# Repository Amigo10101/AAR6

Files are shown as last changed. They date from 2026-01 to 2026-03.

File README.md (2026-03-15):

# AAR6: 6-DOF Robotic Manipulator

AAR6 is a  6-DOF (Degrees of Freedom) desktop robotic arm ecosystem. This project integrates motion control, custom hardware design, and interactive 3D visualization into a unified platform. It is based on the open-source **PAROL6** design by Source Robotics, heavily modified with custom electronics and a robust QP-based differential controller.

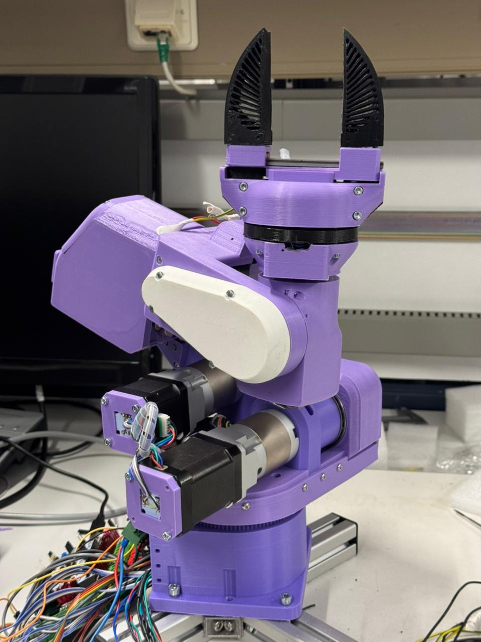
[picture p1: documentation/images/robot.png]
Robot View
 

## 📂 Project Structure

This repository is organized as a monorepo containing all sub-systems of the AAR6 robot:

### 1. [MCU Firmware (STM32)](mcu_firmware/)
The low-level "brain" of the robot, running on an **STM32F446** microcontroller.
- **Real-Time Control**: Implements a 20kHz motion engine for smooth step generation.
- **S-Curve Profiles**: Uses 7-segment S-curve trajectories to minimize jerk and vibrations.
- **Driver Interface**: Communicates with **TMC5160** stepper drivers via SPI.
- **Telemetry**: Streams high-frequency joint states and system health to the host PC.

### 2. [Robot Controller (CPP/QT)](Robot_controller/)
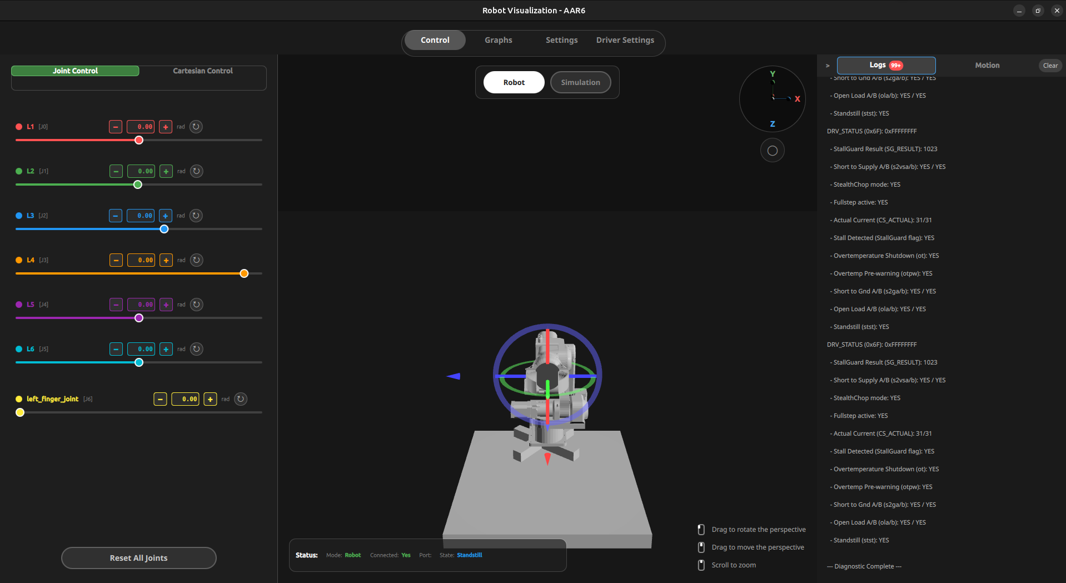
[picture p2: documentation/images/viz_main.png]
Software Interface

The advanced kinematic engine and 3D visualization suite.
- **Kinematics Engine**: High-performance Forward and Inverse Kinematics (FK/IK) implementation.
- **Differential QP Controller**: A singularity-robust solver using Selective Damped Least Squares (SDLS) and Quadratic Programming (OSQP).
- **3D Visualization**: A Qt/QML based interface for real-time monitoring, gizmo-driven movement, and simulator functionality.
- **Collision Checking**: Integrated environment awareness for safe motion planning.

### 3. [Control Board (KiCad)](control_board/)
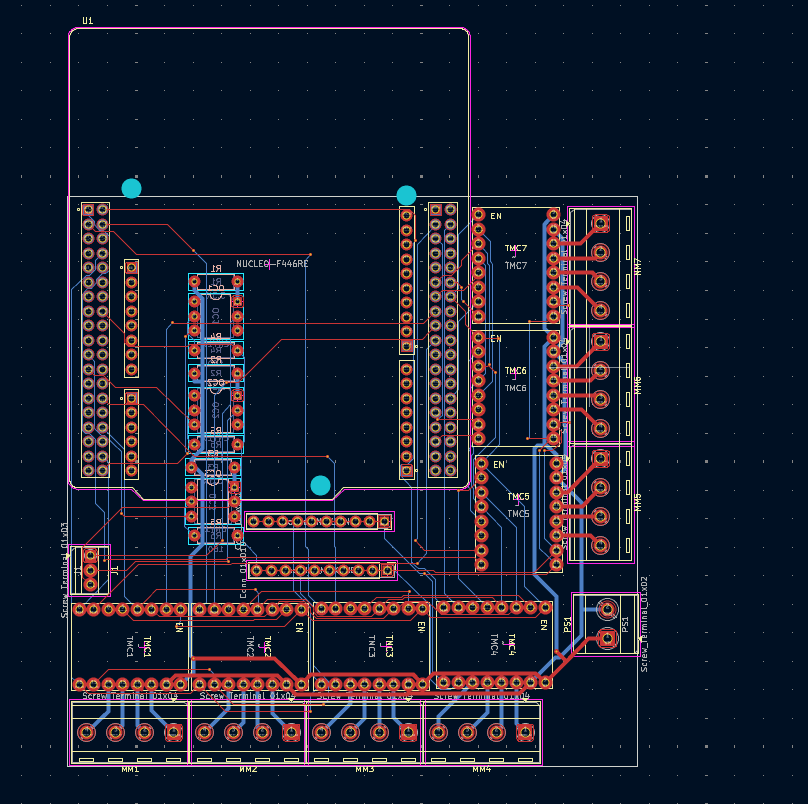
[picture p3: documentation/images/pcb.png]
PCB Design

Custom PCB design (KiCad) that integrates all electronic components.
- **Motor Control**: Supports 7× TMC5160 drivers (6 joints + 1 gripper).
- **Sensor Integration**: Interfaces for AS5600 magnetic encoders and limit switches.
- **Connectivity**: High-speed USB tracking and power distribution logic.

### 4. [ROS 2 Workspace](Robot_ros2_ws/)
Integration layer for the Robot Operating System (ROS 2 Jazzy).
- **Environment**: Containerized ROS 2 development via Docker.
- **Bridging**: Scripts to bridge URDF standalone commands to standard ROS 2 topics.
- **MoveIt Support**: Configuration files for advanced trajectory planning.

### 5. [Documentation](documentation/)
Technical reports, schematics, and academic documentation.
- **Technical Report**: Detailed LaTeX documentation covering mathematics, hardware specs, and software architecture.
- **Schematics**: PDF and image exports of the electrical design.

---

## 🚀 Key Features

- **Singularity Robustness**: Graceful handling of wrist, shoulder, and elbow singularities using adaptive damping.
- **Interactive Control**: Move the robot via 3D gizmos, joint sliders, or direct Cartesian input.
- **Optimized Communication**: 921,600 baud DMA-based serial link for low-latency host-to-MCU coordination.

---

## 🛠️ Components Overview

| Component | Technology | Detail |
| :--- | :--- | :--- |
| **Microcontroller** | STM32F446RET6 | ARM Cortex-M4 @ 180MHz |
| **Motor Drivers** | TMC5160 | 32 microsteps, StallGuard support |
| **GUI Framework** | Qt 6 / QML | Hardware-accelerated 3D rendering |
| **Optimization** | OSQP | Convex Quadratic Programming solver |
| **Communication** | USB-CDC | Custom binary protocol with CRC |

---

## 📜 Documentation & Attribution
- **Mechanical Design**: [PAROL6 by Source Robotics](https://source-robotics.github.io/PAROL-docs/)
- **Core Libraries**:
  - [EAIK (Eigen-based Analytical Inverse Kinematics)](https://github.com/OstermD/EAIK) - Primary analytical seeder for IK.
  - [OSQP (Operator Splitting QP Solver)](https://github.com/osqp) - Numerical optimization for differential control.
  - [FCL (Flexible Collision Library)](https://github.com/flexible-collision-library/fcl) - Real-time collision checking and environment awareness.

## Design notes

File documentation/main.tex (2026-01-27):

%%%%%%%%%%%%%%%%%%%%%%%%%%%%%%%%%%%%%%%%%
% 6-DOF Robotic Arm - Project Report
%%%%%%%%%%%%%%%%%%%%%%%%%%%%%%%%%%%%%%%%%

\documentclass[12pt,a4paper]{report}

% Basic packages
\usepackage[utf8]{inputenc}
\usepackage[T1]{fontenc}
\usepackage{lmodern}
\usepackage[english]{babel}
\usepackage{geometry}
\geometry{margin=2.5cm}

% Graphics
\usepackage{graphicx}
\usepackage{float}

% Tables
\usepackage{booktabs}
\usepackage{tabularx}

% Code listings
\usepackage{listings}
\usepackage{xcolor}

% Math
\usepackage{amsmath}
\usepackage{amssymb}

% TikZ for diagrams
\usepackage{tikz}
\usetikzlibrary{shapes,arrows,positioning,fit}

% Hyperlinks
\usepackage{hyperref}
\hypersetup{colorlinks=true, linkcolor=blue!60!black}

% Code style
\lstset{
    basicstyle=\ttfamily\small,
    breaklines=true,
    frame=single,
    backgroundcolor=\color{gray!10}
}

%% ========================================
%% DOCUMENT INFO
%% ========================================

\title{
    \vspace{2cm}
    {\Huge\bfseries Design and Implementation of a}\\[0.3cm]
    {\Huge\bfseries 6-DOF Robotic Manipulator}\\[0.5cm]
    {\Huge\bfseries with Singularity-Robust Motion Control}\\[0.8cm]
    {\LARGE Project Report}\\
    \vspace{2cm}
}

\author{
    Anwesh Rijal (16940572) \\
    Austin Mathew Palamoottil (26044014) \\
    \textit{Hochschule Ravensburg-Weingarten University}
}

\date{
    January 2026
}

%% ========================================
%% DOCUMENT
%% ========================================

\begin{document}

% Title page
\maketitle
\thispagestyle{empty}
\newpage

% Table of contents
\tableofcontents
\newpage

%% ========================================
%% PART 1: INTRODUCTION
%% ========================================

\chapter{Introduction}

\section{Project Background}

This project involves the development of a 6-DOF robotic arm control system, including custom firmware and host software. The mechanical design is based on the open-source \textbf{PAROL6} desktop robot arm developed by Source Robotics.

\subsection{Base Design Attribution}

The robot hardware design used in this project is derived from:

\begin{itemize}
    \item \textbf{PAROL6 Desktop Robot Arm} by Source Robotics
    \item Design by Petar Crnjak (\url{https://github.com/PCrnjak})
    \item Documentation: \url{https://source-robotics.github.io/PAROL-docs/}
    \item Hardware: \url{https://github.com/PCrnjak/PAROL6-Desktop-robot-arm}
\end{itemize}

This project extends the base PAROL6 design with custom firmware and software implementations.

\section{Project Objectives}

The primary objectives of this project are:

\begin{enumerate}
    \item \textbf{Build a Fully Functional 6-DOF Robotic Arm}: Assemble and integrate the mechanical structure, stepper motors, control electronics, and end effector into a working desktop manipulator.
    
    \item \textbf{Develop Stable Motion Control Software}: Implement a robust inverse kinematics controller capable of smooth, singularity-free motion throughout the workspace.
    
    \item \textbf{Implement Real-Time Control}: Create firmware and host software that can execute motion commands with low latency and high precision.
\end{enumerate}

\subsection{Controller Objectives}

The motion controller specifically aims to:
\begin{itemize}
    \item Provide stable velocity-level IK using quadratic programming (QP)
    \item Handle kinematic singularities gracefully using adaptive damping
    \item Support real-time interactive control via visualization interface
    \item Respect joint position and velocity limits at all times
\end{itemize}

\subsection{Software Architecture}

The control software consists of two main components:

\begin{itemize}
    \item \textbf{MCU Firmware} (STM32F446): Handles low-level motor control, step generation, S-curve motion profiles, and serial communication with the host.
    
    \item \textbf{Host Software} (C++/Qt): Implements kinematics computation (FK/IK), the QP-based differential controller with singularity handling, and 3D visualization for interactive control.
\end{itemize}

\section{Scope}

This project covers:
\begin{itemize}
    \item Mechanical assembly of the PAROL6-based robot arm
    \item Custom control board with STM32F446 and TMC5160 drivers
    \item MCU firmware for motion execution
    \item Host-side kinematics and motion control software
    \item 3D visualization and user interface
\end{itemize}

\section{Document Structure}

\begin{itemize}
    \item \textbf{Chapter 2 - Hardware}: Robot mechanical design, control board, electrical connections
    \item \textbf{Chapter 3 - MCU Firmware}: Motor control, S-curve profiles, communication
    \item \textbf{Chapter 4 - Motion Control Software}: Kinematics, QP-based differential controller, visualization
    \item \textbf{Appendices}: Pinout, DH parameters, joint limits
\end{itemize}

%% ========================================
%% PART 2: HARDWARE
%% ========================================

\chapter{Hardware}

This chapter describes the physical hardware of the our robotic arm system.

%% --- Section 1: The Robot ---
\section{The Robot}

\subsection{Overview}

Our robot is based on the \textbf{PAROL6} open-source robot arm design by Source Robotics. It is a 6 degrees of freedom (6-DOF) desktop robotic arm designed for education, research, and light industrial applications. The robot features an articulated arm configuration with all revolute joints, providing full spatial manipulation capability.

The mechanical design, including 3D printed parts and assembly, follows the original PAROL6 specifications with modifications for this project.

\begin{table}[H]
    \centering
    \begin{tabular}{|l|l|}
        \hline
        \textbf{Parameter} & \textbf{Value} \\
        \hline
        Degrees of Freedom & 6 rotating joints \\
        Weight & 5.5 kg \\
        Power Consumption & 40 W \\
        Material & 3D printed ABS plastic \\
        Communication & USB \\
        \hline
    \end{tabular}
    \caption{Robot Specifications}
    \label{tab:robot_specs}
\end{table}

\subsection{Mechanical Structure}

The robot is constructed primarily from 3D printed ABS plastic. ABS provides good mechanical strength and thermal resistance for this application.

\subsubsection{Joint Configuration}

\begin{table}[H]
    \centering
    \begin{tabular}{|c|l|c|l|}
        \hline
        \textbf{Joint} & \textbf{Function} & \textbf{Range} & \textbf{Reduction} \\
        \hline
        J1 & Base rotation & 250° & Belt 6.4:1 \\
        J2 & Shoulder lift & 141° & Planetary 20:1 \\
        J3 & Elbow bend & 180° & Planetary 20:1 + Belt 38:42 \\
        J4 & Wrist rotation & 212° & Belt 4:1 \\
        J5 & Wrist pitch & 180° & Belt 4:1 \\
        J6 & Tool rotation & $\infty$ & Planetary 10:1 \\
        \hline
    \end{tabular}
    \caption{Joint Configuration and Reduction Ratios}
    \label{tab:joint_config}
\end{table}

\subsubsection{Spherical Wrist Design}

The robot uses a \textbf{spherical wrist} configuration, where the last three joint axes (J4, J5, J6) intersect at a single point called the wrist center. This design is common in industrial manipulators and simplifies inverse kinematics by decoupling position and orientation problems.

\subsubsection{Kinematic Singularities}

Singularities are configurations where the robot loses one or more degrees of freedom. For our 6-DOF spherical wrist arm, three main singularities exist:

\begin{enumerate}
    \item \textbf{Wrist Singularity}: Occurs when J4 and J6 axes align (J5 = 0° or 180°)
    \item \textbf{Shoulder Singularity}: Wrist center lies on the J1 axis
    \item \textbf{Elbow Singularity}: Arm fully extended or folded
\end{enumerate}

Near singularities, the inverse Jacobian produces very large joint velocities, causing instability. Our software mitigates this using adaptive damping techniques (see Chapter 4).

\subsection{Actuators}

All joints use stepper motors with the following configuration:

\begin{itemize}
    \item \textbf{Motor type}: NEMA 17 / NEMA 23 stepper motors
    \item \textbf{Steps per revolution}: 200 (1.8° step angle)
    \item \textbf{Microstepping}: 32 microsteps (6400 steps/revolution)
    \item \textbf{Drivers}: TMC5160 (BigTreeTech) with StallGuard \cite{tmc5160_prod}
    \item \textbf{Gearboxes}: Precision planetary gearboxes and belt drives
\end{itemize}

\subsubsection{Step Resolution}

With 32 microstepping and gear reduction, the theoretical step resolution at each joint:

\begin{table}[H]
    \centering
    \begin{tabular}{|c|c|c|}
        \hline
        \textbf{Joint} & \textbf{Resolution (rad)} & \textbf{Resolution (deg)} \\
        \hline
        J1 & 0.000153 & 0.00879° \\
        J2 & 0.000049 & 0.00281° \\
        J3 & 0.000054 & 0.00311° \\
        J4 & 0.000245 & 0.01406° \\
        J5 & 0.000245 & 0.01406° \\
        J6 & 0.000098 & 0.00563° \\
        \hline
    \end{tabular}
    \caption{Joint Step Resolution (after gear reduction)}
    \label{tab:step_resolution}
\end{table}

\subsection{Sensors}

\begin{itemize}
    \item \textbf{Position sensing}: AS5600 magnetic encoders for closed-loop position feedback
    \item \textbf{Limit switches}: Used for homing and end-of-travel protection
\end{itemize}

\subsection{End Effector}

The end effector is a custom-designed electric gripper based on the \textbf{SSG-48 Adaptive Electric Gripper} by Source Robotics (\url{https://github.com/PCrnjak/SSG-48-adaptive-electric-gripper}).

\subsubsection{Gripper Redesign}

The original SSG-48 design was heavily modified for this project:

\begin{itemize}
    \item \textbf{Actuation}: Replaced original motor with a stepper motor for precise position control
    \item \textbf{Position Feedback}: Added AS5600 magnetic encoder for closed-loop gripper position sensing
    \item \textbf{Control}: Integrated with the main control system for coordinated motion
\end{itemize}

\subsubsection{Gripper Specifications}

\begin{table}[H]
    \centering
    \begin{tabular}{|l|l|}
        \hline
        \textbf{Parameter} & \textbf{Value} \\
        \hline
        Actuation & Stepper motor \\
        Position Sensor & AS5600 magnetic encoder \\
        Control Mode & Closed-loop position \\
        Base Design & SSG-48 (Source Robotics) \\
        \hline
    \end{tabular}
    \caption{Gripper Specifications}
    \label{tab:gripper_specs}
\end{table}

%% --- Section 2: Control Board ---
\section{Control Board}

\subsection{Overview}

A custom PCB was designed to integrate all control electronics for the robot. The board serves as the central interface between the STM32 microcontroller and all motor drivers, sensors, and power systems.

% TODO: Add PCB image
\begin{figure}[H]
    \centering
    
    \caption{Control Board PCB Layout}
    \label{fig:control_board_pcb}
\end{figure}

% TODO: Add 3D render
\begin{figure}[H]
    \centering
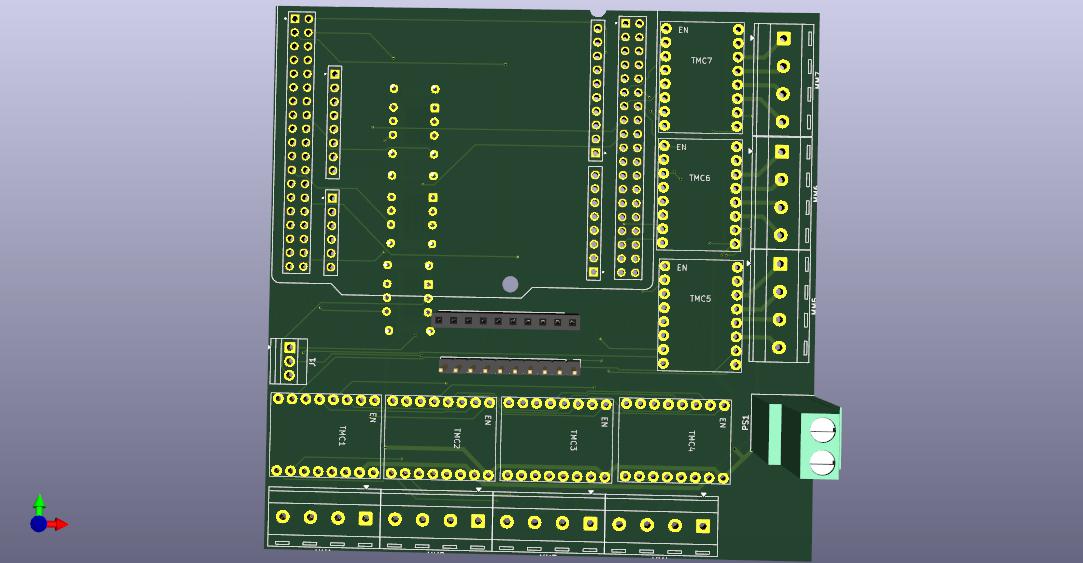
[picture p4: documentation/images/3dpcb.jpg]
    
    \caption{Control Board 3D View}
    \label{fig:control_board_3d}
\end{figure}

\subsubsection{Key Features}

\begin{itemize}
    \item \textbf{MCU Interface}: Socket for STM32 Nucleo development board
    \item \textbf{Motor Drivers}: 7× TMC5160 BigTreeTech driver slots (6 robot joints + 1 gripper)
    \item \textbf{Motor Outputs}: Connectors for all stepper motors
    \item \textbf{Limit Switches}: Input connectors for all joint limit switches
    \item \textbf{Power Interface}: Motor power input and distribution
\end{itemize}

\subsection{Microcontroller}

The control board uses an \textbf{STM32 Nucleo} development board as the main processor:
\begin{itemize}
    \item Plugs into dedicated socket on the control board
    \item Provides all GPIO, timer, and communication interfaces
    \item USB connection for host communication
    \item Firmware development and debugging via ST-Link
\end{itemize}

\subsection{Motor Drivers}

The board accommodates 7 \textbf{TMC5160 BigTreeTech} stepper drivers:

\begin{table}[H]
    \centering
    \begin{tabular}{|c|l|l|}
        \hline
        \textbf{Slot} & \textbf{Function} & \textbf{Motor} \\
        \hline
        1 & Joint 1 & Base rotation \\
        2 & Joint 2 & Shoulder \\
        3 & Joint 3 & Elbow \\
        4 & Joint 4 & Wrist 1 \\
        5 & Joint 5 & Wrist 2 \\
        6 & Joint 6 & Wrist 3 \\
        7 & Gripper & End effector \\
        \hline
    \end{tabular}
    \caption{Motor Driver Assignments}
    \label{tab:driver_assignments}
\end{table}

\subsection{Power System}

\begin{itemize}
    \item \textbf{Motor Power}: Direct connection for motor supply voltage
    \item \textbf{Logic Power}: Regulated from motor supply or USB
\end{itemize}

\subsection{Connectors}

\begin{itemize}
    \item \textbf{Motor outputs}: 7× stepper motor connectors (4-pin)
    \item \textbf{Limit switches}: Input connectors for each joint
    \item \textbf{Encoder inputs}: For AS5600 position feedback
    \item \textbf{Power input}: Main power connector
\end{itemize}

%% --- Section 3: Electrical Connections ---
\section{Electrical Connections}

This section presents the schematic diagrams for the main electrical subsystems.

\subsection{MCU Connections}

The STM32 Nucleo board interfaces with all other subsystems:

\begin{figure}[H]
    \centering
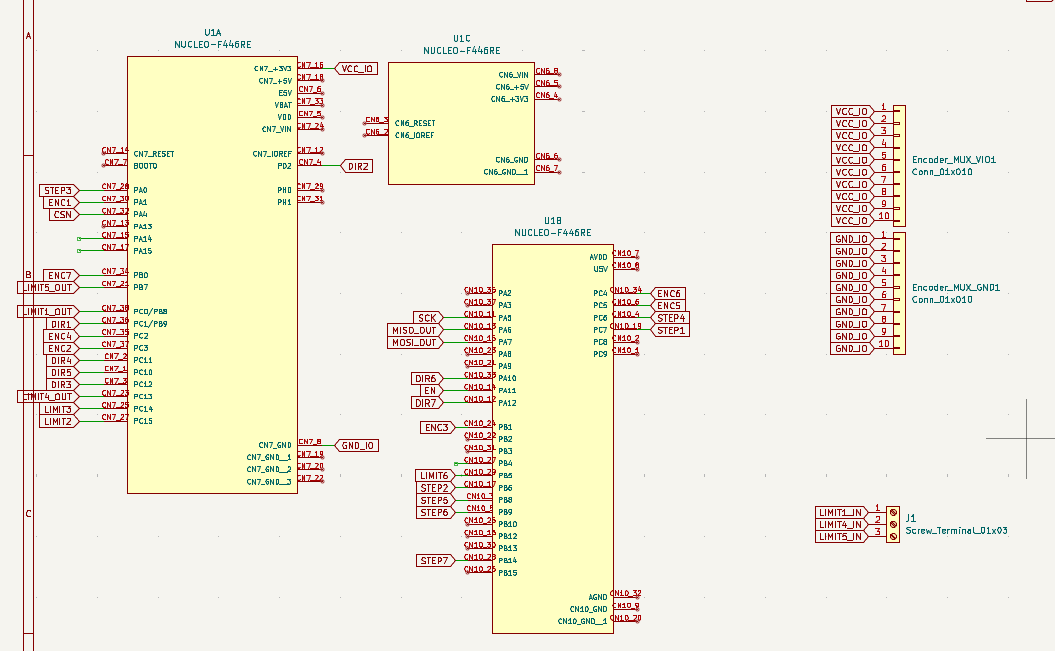
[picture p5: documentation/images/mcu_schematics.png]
    
    \caption{MCU Schematic - STM32 Nucleo Connections}
    \label{fig:mcu_schematic}
\end{figure}

\subsection{Motor Driver Wiring}

The TMC5160 motor drivers are connected via \textbf{SPI daisy chain} configuration. This allows all 7 drivers to share a single SPI bus, reducing the number of required GPIO pins.

\begin{figure}[H]
    \centering
    
    \caption{Motor Driver Schematic - SPI Daisy Chain Configuration}
    \label{fig:motor_schematic}
\end{figure}

\subsubsection{SPI Daisy Chain}

In daisy chain mode:
\begin{itemize}
    \item All drivers share common SCK (clock) and CS (chip select) lines
    \item Data passes from SDO of one driver to SDI of the next
    \item Single SPI transaction addresses all 7 drivers sequentially
    \item Reduces wiring complexity and MCU pin usage
\end{itemize}

\subsection{Limit Switch Wiring}

Each joint has a limit switch for homing and end-of-travel protection:

\begin{figure}[H]
    \centering
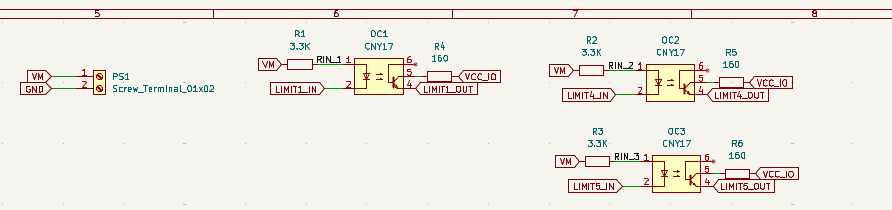
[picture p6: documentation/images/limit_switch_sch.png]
    
    \caption{Limit Switch Schematic}
    \label{fig:limit_switch_schematic}
\end{figure}

%% ========================================
%% PART 3: MCU FIRMWARE
%% ========================================

\chapter{MCU Firmware}

This chapter describes the firmware running on the STM32 Nucleo microcontroller.

\section{Firmware Overview}

The MCU firmware is responsible for real-time motor control, sensor reading, and communication with the host. It uses FreeRTOS for task management.

\subsection{System Architecture}

\begin{figure}[H]
    \centering
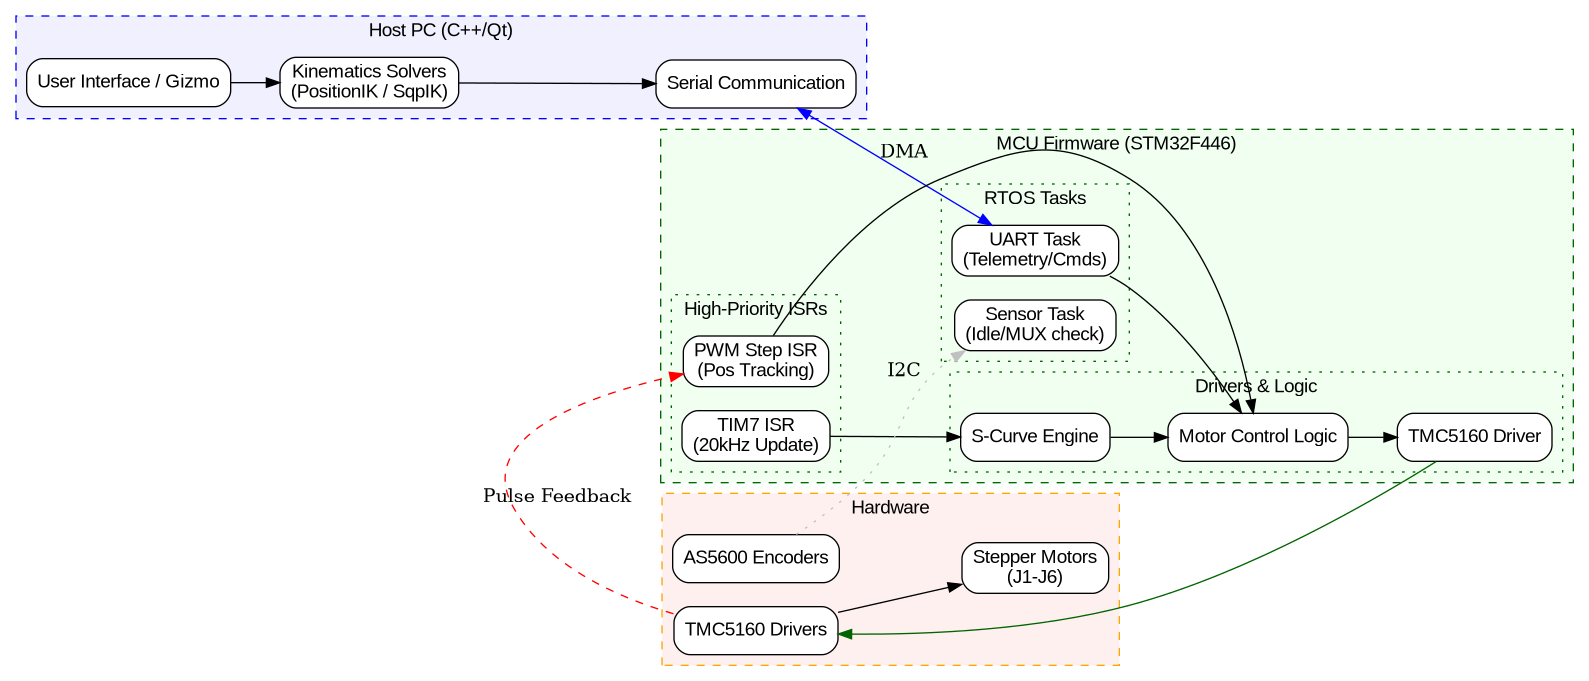
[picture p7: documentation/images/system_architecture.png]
    
    \caption{System Architecture and Data Flow across Host PC, MCU, and Hardware}
    \label{fig:system_architecture}
\end{figure}

\subsection{RTOS Tasks}

The firmware utilizes a hybrid architecture combining high-frequency interrupts for motion control with RTOS tasks for communication and low-priority monitoring:

\begin{table}[H]
    \centering
    \begin{tabular}{|l|l|l|}
        \hline
        \textbf{Component} & \textbf{Priority/Rate} & \textbf{Function} \\
        \hline
        TIM7 ISR & 20\,kHz & S-Curve engine update, PWM frequency modulation \\
        PWM Step ISR & Event-based & Real-time position tracking, target-reached stopping \\
        UART Task & High & DMA-based telemetry streaming and command parsing \\
        Sensor Task & Low & PCA9548A MUX detection and health monitoring \\
        \hline
    \end{tabular}
    \caption{Real-Time Software Components}
    \label{tab:realtime_components}
\end{table}

\section{Motor Control}

\subsection{TMC5160 Driver Interface}

The firmware communicates with TMC5160 drivers via SPI:
\begin{itemize}
    \item Daisy chain configuration for all 7 drivers
    \item Register access for current, velocity, and position control
    \item StallGuard feedback for sensorless homing
\end{itemize}

\subsection{Step Generation}

Motor steps are generated using hardware timers:
\begin{itemize}
    \item Timer-based step pulse generation
    \item Velocity and acceleration limiting
    \item Smooth start/stop transitions
\end{itemize}

The firmware implements a high-performance 7-segment S-Curve motion profile to ensure continuous acceleration and minimize mechanical vibrations. Unlike standard trapezoidal profiles, the S-Curve limits the third derivative of position (jerk), preventing the "infinite jerk" spikes that lead to motor skipping and structural resonance.

\subsection{Mathematical Foundation}

The motion profile is governed by the constant jerk $J$, which is the rate of change of acceleration $a$. The kinematic states are derived through successive integration:

\begin{equation}
    a(t) = a_0 + \int_{0}^{t} J(\tau) d\tau
\end{equation}
\begin{equation}
    v(t) = v_0 + \int_{0}^{t} a(\tau) d\tau = v_0 + a_0 t + \frac{1}{2} J t^2
\end{equation}
\begin{equation}
    s(t) = s_0 + \int_{0}^{t} v(\tau) d\tau = s_0 + v_0 t + \frac{1}{2} a_0 t^2 + \frac{1}{6} J t^3
\end{equation}

\subsection{The 7-Segment Profile}

A full point-to-point motion consists of seven distinct phases:

\begin{enumerate}
    \item \textbf{Jerk-up}: Jerk is constant ($+J_{max}$), acceleration increases linearly.
    \item \textbf{Constant Accel}: Jerk is zero, acceleration is constant ($a_{max}$).
    \item \textbf{Jerk-down}: Jerk is constant ($-J_{max}$), acceleration decreases to zero as velocity reaches the maximum setpoint.
    \item \textbf{Constant Velocity}: Jerk and acceleration are zero.
    \item \textbf{Jerk-down}: Jerk is constant ($-J_{max}$), acceleration linearly decreases (deceleration increases).
    \item \textbf{Constant Decel}: Jerk is zero, deceleration is constant ($-a_{max}$).
    \item \textbf{Jerk-up}: Jerk is constant ($+J_{max}$), deceleration returns to zero as the target position is reached.
\end{enumerate}

\subsection{Implementation Strategy}

The firmware executes this engine within the \textbf{TIM7 ISR at 20\,kHz}. This high frequency (50\,$\mu$s ticks) allows for quasi-continuous updates of the output PWM frequency, ensuring the motor follows the ideal curve with negligible quantization error.

\subsubsection{Adaptive Deceleration}
Because the MCU must handle dynamic target updates and external interruptions, the engine does not simply "blindly" run a pre-calculated curve. Instead, it performs a \textbf{deceleration check every 1\,ms}:
\begin{itemize}
    \item It continuously calculates the \textit{stopping distance} required to reach zero velocity from the current speed using maximum jerk/decel limits.
    \item When the \textit{remaining distance} to the target is less than or equal to the stopping distance, it triggers the transition from constant velocity to the deceleration phases (Phase 5).
    \item \textbf{Overshoot Correction}: In the final pulses (Phase 7), any remaining floating-point error is compensated by an adaptive "dist-remove-per-cycle" calculation, guaranteeing that the final pulse lands exactly on the integer step target.
\end{itemize}

\section{Communication Protocol}

Communication with the host software is implemented over a high-speed USB-CDC serial link (baud rate 921,600). The protocol uses a robust binary framing to ensure data integrity and low latency.

\subsection{Framing Structure}
All packets, regardless of direction, share a common header and footer structure:
\begin{itemize}
    \item \textbf{Start Frame}: \texttt{0xAA 0x55} (2 bytes)
    \item \textbf{Length}: Payload size (2 bytes, Little-Endian)
    \item \textbf{Payload}: Actual data (variable length)
    \item \textbf{Checksum}: XOR sum of all payload bytes (1 byte)
\end{itemize}

\subsection{Outgoing Format (MCU $\rightarrow$ PC)}
The MCU streams telemetry at 100\,Hz. The primary telemetry packet (Type \texttt{0x01}) payload consists of:
\begin{itemize}
    \item \textbf{Joint Data}: 6 joints $\times$ (Position, Velocity, Acceleration) as 32-bit floats (72 bytes total)
    \item \textbf{Robot State}: 1 byte integer (Current operational mode)
\end{itemize}

\subsection{Incoming Format (PC $\rightarrow$ MCU)}
The host sends control and motion commands. The payload structure varies by command type:
\begin{itemize}
    \item \textbf{State Commands}: 1 byte (e.g., CMD\_ESTOP, CMD\_HOME)
    \item \textbf{Motion Commands}: 2 bytes (Command Type + Action) followed by 6 joints $\times$ (Position, Velocity) as 32-bit floats (50 bytes total)
\end{itemize}

%% ========================================
%% PART 4: URDF STANDALONE & MOTION CONTROL
%% ========================================

\chapter{Motion Control Software and Kinematics}

This chapter describes the kinematics theory and the host-side software for computation and control.

\section{Kinematics Theory}

Kinematics describes the motion of the robot without considering the forces that cause it. For our 6-DOF arm, we define the relationship between joint space $\mathbf{q} \in \mathbb{R}^6$ and task space $\mathbf{x} \in SE(3)$.

\subsection{Forward Kinematics}

Forward Kinematics (FK) is the mathematical process of determining the pose (position and orientation) of the end-effector given a set of joint angles. For a 6-DOF manipulator like our arm, this involves mapping a vector of joint angles $\mathbf{q} = [q_1, q_2, q_3, q_4, q_5, q_6]^T$ to a homogeneous transformation matrix ${}^0T_6 \in SE(3)$.

\begin{figure}[H]
    \centering
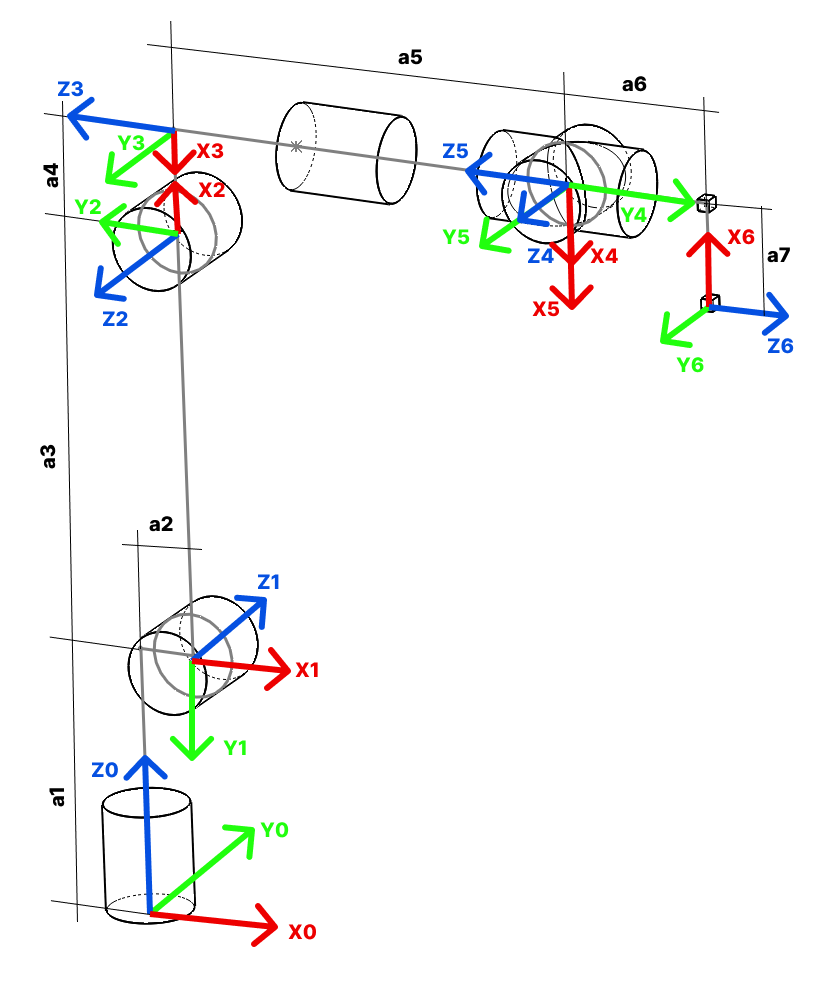
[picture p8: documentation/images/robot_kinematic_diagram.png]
    
    \caption{Robot Kinematic Diagram showing joint axes and coordinate frames}
    \label{fig:kinematic_diagram}
\end{figure}

\subsubsection{The Denavit-Hartenberg (DH) Convention}

To systematically represent the relationship between adjacent links, we adopt the \textbf{Standard Denavit-Hartenberg (DH)} convention. This method assigns a coordinate frame to each joint and describes the transformation from frame $i-1$ to frame $i$ using four parameters:

\begin{itemize}
    \item \textbf{Joint Angle} ($\theta_i$): Rotation about the $z_{i-1}$ axis. This is the variable component for revolute joints.
    \item \textbf{Link Offset} ($d_i$): Distance along the $z_{i-1}$ axis from the origin of frame $i-1$ to the common normal between $z_{i-1}$ and $z_i$.
    \item \textbf{Link Length} ($a_i$): Distance along the $x_i$ axis (the common normal) between the $z_{i-1}$ and $z_i$ axes.
    \item \textbf{Link Twist} ($\alpha_i$): Rotation about the $x_i$ axis required to align $z_{i-1}$ with $z_i$.
\end{itemize}

The individual transformation matrix ${}^{i-1}T_i$ is the result of four successive operations: $Rot_z(\theta_i) \to Trans_z(d_i) \to Trans_x(a_i) \to Rot_x(\alpha_i)$.

\begin{equation}
    {}^{i-1}T_i = 
    \begin{bmatrix}
    \cos\theta_i & -\sin\theta_i\cos\alpha_i & \sin\theta_i\sin\alpha_i & a_i\cos\theta_i \\
    \sin\theta_i & \cos\theta_i\cos\alpha_i & -\cos\theta_i\sin\alpha_i & a_i\sin\theta_i \\
    0 & \sin\alpha_i & \cos\alpha_i & d_i \\
    0 & 0 & 0 & 1
    \end{bmatrix}
\end{equation}

\subsubsection{Robot DH Parameters}

Based on the physical dimensions of our robot arm, the following DH parameters define the kinematic chain. The base height $H_1$, link lengths $L_2, L_3$, and wrist offsets $W_1, W_2$ are derived from the URDF model.

\begin{figure}[H]
    \centering
    \begin{minipage}{0.48\textwidth}
        \centering
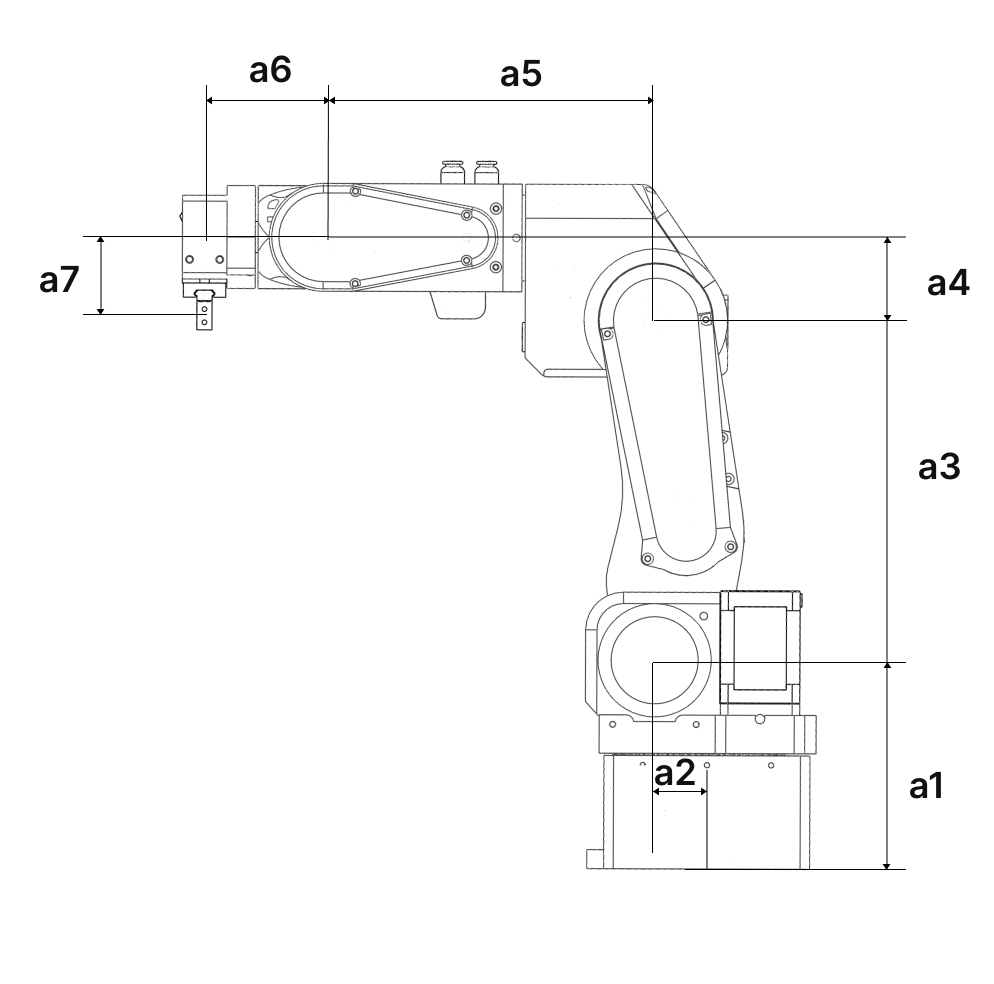
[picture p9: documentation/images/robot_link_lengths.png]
        
        \caption{Physical Link Lengths}
        \label{fig:link_lengths}
    \end{minipage}
    \hfill
    \begin{minipage}{0.48\textwidth}
        \centering
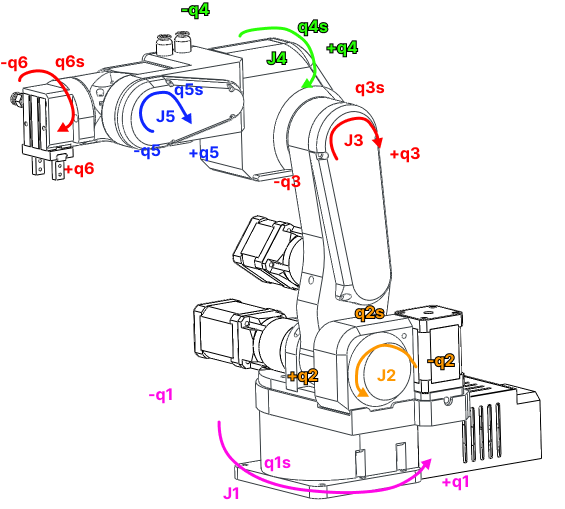
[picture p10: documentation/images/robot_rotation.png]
        
        \caption{Joint Rotation Directions}
        \label{fig:robot_rotation}
    \end{minipage}
\end{figure}

\begin{table}[H]
    \centering
    \begin{tabular}{|c|c|c|c|c|}
        \hline
        \textbf{Link} & $\theta_i$ & $d_i$ & $a_i$ & $\alpha_i$ \\
        \hline
        1 & $q_1$ & $110.5\,$mm & $23.4\,$mm & $-90^\circ$ \\
        2 & $q_2$ & $0\,$mm & $180.0\,$mm & $180^\circ$ \\
        3 & $q_3$ & $0\,$mm & $43.5\,$mm & $90^\circ$ \\
        4 & $q_4$ & $176.35\,$mm & $0\,$mm & $-90^\circ$ \\
        5 & $q_5$ & $0\,$mm & $51.0\,$mm & $90^\circ$ \\
        6 & $q_6$ & $52.0\,$mm & $0\,$mm & $0^\circ$ \\
        \hline
    \end{tabular}
    \caption{DH Parameters for the 6-DOF Robot Arm}
    \label{tab:dh_parameters}
\end{table}

The total transformation from the base to the end-effector is obtained by multiplying these matrices in sequence:
\begin{equation}
    {}^{0}T_{ee}(\mathbf{q}) = {}^{0}T_1(q_1) \cdot {}^{1}T_2(q_2) \cdot {}^{2}T_3(q_3) \cdot {}^{3}T_4(q_4) \cdot {}^{4}T_5(q_5) \cdot {}^{5}T_6(q_6)
\end{equation}

\subsubsection{End-Effector Pose Extraction}

The resulting $4 \times 4$ homogeneous transformation matrix ${}^0T_{ee}$ contains the full pose information relative to the base frame. It is partitioned as follows:

\begin{equation}
    {}^0T_{ee} = \begin{bmatrix}
    \mathbf{n} & \mathbf{s} & \mathbf{a} & \mathbf{p} \\
    0 & 0 & 0 & 1
    \end{bmatrix} = \begin{bmatrix}
    r_{11} & r_{12} & r_{13} & p_x \\
    r_{21} & r_{22} & r_{23} & p_y \\
    r_{31} & r_{32} & r_{33} & p_z \\
    0 & 0 & 0 & 1
    \end{bmatrix}
\end{equation}

where:
\begin{itemize}
    \item \textbf{Position}: The vector $\mathbf{p} = [p_x, p_y, p_z]^T$ represents the Cartesian coordinates of the end-effector origin.
    \item \textbf{Orientation}: The $3 \times 3$ submatrix $\mathbf{R} = [\mathbf{n}, \mathbf{s}, \mathbf{a}]$ represents the rotation of the end-effector. The columns $\mathbf{n}$ (normal), $\mathbf{s}$ (sliding), and $\mathbf{a}$ (approach) are unit vectors defining the orientation of the final link's axes in the base frame.
\end{itemize}

In our software, this position vector and rotation matrix are used directly for error computation in the numerical solvers and for visualization in the 3D interface.

\subsection{The Jacobian Matrix}

The Jacobian matrix $\mathbf{J}(\mathbf{q})$ is a fundamental operator in robotics that maps velocities from joint space to task space. For our 6-DOF manipulator, it relates the joint velocity vector $\dot{\mathbf{q}} \in \mathbb{R}^6$ to the end-effector twist $\mathbf{\xi} = [\mathbf{v}, \mathbf{\omega}]^T \in \mathbb{R}^6$:

\begin{equation}
    \begin{bmatrix} \mathbf{v} \\ \mathbf{\omega} \end{bmatrix} = \mathbf{J}(\mathbf{q}) \dot{\mathbf{q}}
\end{equation}

where $\mathbf{v}$ is the linear velocity and $\mathbf{\omega}$ is the angular velocity of the end-effector.

\subsubsection{Geometric Jacobian Derivation}

The Jacobian is composed of six columns, $\mathbf{J} = [\mathbf{j}_1, \mathbf{j}_2, \dots, \mathbf{j}_6]$, where each column represents the contribution of a single joint to the end-effector velocity. Since all joints in our robot are revolute, the $i$-th column is derived geometrically as:

\begin{equation}
    \mathbf{j}_i = \begin{bmatrix} \mathbf{z}_{i-1} \times (\mathbf{p}_{ee} - \mathbf{p}_{i-1}) \\ \mathbf{z}_{i-1} \end{bmatrix}
\end{equation}

where:
\begin{itemize}
    \item $\mathbf{z}_{i-1}$ is the unit vector along the axis of rotation of joint $i$.
    \item $\mathbf{p}_{ee}$ is the position of the end-effector in the base frame.
    \item $\mathbf{p}_{i-1}$ is the position of the origin of frame $i-1$ in the base frame.
\end{itemize}

The Jacobian is highly configuration-dependent. When $\mathbf{J}(\mathbf{q})$ becomes singular (loses rank), the robot loses one or more degrees of freedom in task space. This occurs when joint axes align or the arm reaches its workspace boundaries.

\subsection{Singularity Handling: Selectively Damped Least Squares}

To maintain stability near singularities, we utilize the \textbf{Selectively Damped Least Squares (SDLS)} method. Unlike standard Damped Least Squares (Tikhonov regularization) which adds a uniform penalty to all joints, SDLS specifically targets only the singular directions in the task space.

Through Singular Value Decomposition (SVD), the Jacobian is decomposed as:
\begin{equation}
    \mathbf{J} = \mathbf{U} \mathbf{\Sigma} \mathbf{V}^T
\end{equation}
where the columns of $\mathbf{V}$ are joint-space vectors. We construct a damping matrix $\mathbf{\Lambda}$ that acts only in the basis of these vectors:
\begin{equation}
    \mathbf{\Lambda} = \sum_{i=1}^{n} \lambda_i^2 \mathbf{v}_i \mathbf{v}_i^T
\end{equation}
The per-mode damping factor $\lambda_i$ is computed based on the singular value $\sigma_i$:
\begin{equation}
    \lambda_i = \begin{cases} 
    \lambda_{max} \left(1 - \frac{\sigma_i}{\sigma_{threshold}}\right)^2 & \text{if } \sigma_i < \sigma_{threshold} \\
    0 & \text{otherwise}
    \end{cases}
\end{equation}
This approach ensures that "healthy" directions remain precise while "singular" directions are smoothly constrained, preventing infinite joint speeds and numerical instability.

\subsection{Inverse Kinematics}

Inverse Kinematics (IK) is the process of finding the joint angles $\mathbf{q}$ that result in a desired end-effector pose. Unlike FK, IK is non-linear and can have multiple solutions, or no solution if the target is outside the workspace.

\subsubsection{Analytical Inverse Kinematics}

Analytical (closed-form) Inverse Kinematics is the process of finding joint angles $\mathbf{q}$ algebraically. Our robot's architecture allows for a \textbf{kinematic decoupling} strategy, which divides the 6-DOF problem into two smaller, independent subproblems: a 3-DOF positional problem and a 3-DOF orientational problem.

\paragraph{1. Kinematic Decoupling (Wrist Center)}

The key requirement for decoupling is that the axes of the last three joints (Joints 4, 5, and 6) intersect at a single point, known as the \textbf{wrist center} ($P_w$). Because rotational motion of the wrist does not move $P_w$, its position is determined solely by the first three joints.

Given a target end-effector position $\mathbf{p}_{target}$ and its approach vector $\mathbf{a}$ (the $z$-axis of the end-effector frame), the wrist center is calculated as:
\begin{equation}
    \mathbf{p}_w = \mathbf{p}_{target} - d_6 \cdot \mathbf{a}
\end{equation}
where $d_6 = 52.0\,$mm is the distance from the wrist center to the end-effector tip.

\paragraph{2. Solving for the Arm (Joints 1, 2, 3)}

With $\mathbf{p}_w = [x_w, y_w, z_w]^T$ known in the base coordinate frame:
\begin{itemize}
    \item \textbf{Base Rotation ($q_1$)}: The first joint rotates the entire arm to align with the $x-y$ projection of the wrist center:
    \begin{equation}
        q_1 = \operatorname{atan2}(y_w, x_w) \quad (\text{or } q_1 + \pi \text{ for reversed base})
    \end{equation}
    \item \textbf{Planar Geometry ($q_2, q_3$)}: Once $q_1$ is fixed, the problem simplifies to a 2D planar linkage. We solve for $q_2$ and $q_3$ using the \textbf{Law of Cosines} based on the triangle formed by $L_2$, $L_3$, and the radial distance to $P_w$. This step yields two solutions per base configuration: \textit{Elbow Up} and \textit{Elbow Down}.
\end{itemize}

\paragraph{3. Solving for the Wrist (Joints 4, 5, 6)}

After calculating the arm joints, the rotation matrix from the base to Joint 3, ${}^{0}R_3$, is fully defined. To reach the target orientation $\mathbf{R}_{target}$, the wrist must provide the remaining rotation ${}^{3}R_6$:
\begin{equation}
    {}^{3}R_6 = ({}^{0}R_3)^T \cdot \mathbf{R}_{target}
\end{equation}
The matrix ${}^{3}R_6$ corresponds to a standard \textbf{Z-Y-Z Euler sequence} defined by the wrist joints $q_4, q_5, q_6$. Equating the elements of ${}^{3}R_6$ to the Euler rotation matrix allows us to extract the angles:
\begin{equation}
    q_5 = \pm \operatorname{acos}(R_{33}) \quad (\text{where } R_{33} \text{ is the bottom-right element})
\end{equation}
The choice of sign for $q_5$ defines the \textbf{Wrist Flip} (normalized vs. flipped configuration).

\paragraph{4. Solution Selection and Configuration Ranking}

For any reachable target, the analytical solver \cite{EAIK} generates a candidate set of up to \textbf{8 valid solutions} (2 Base $\times$ 2 Elbow $\times$ 2 Wrist). Because analytical IK can be discontinuous—exhibiting "jerk" between branches—our solver utilizes a ranking and blending system to select the most stable solution:

\begin{itemize}
    \item \textbf{Configuration Hysteresis}: A large "Branch Penalty" is applied to solutions that require a change in the robot's fundamental mode (e.g., flipping the base or elbow). This ensures the robot stays within its current kinematic branch as long as it is reachable.
    \item \textbf{Singularity-Aware Metric}: Standard Euclidean distance is insufficient near singularities. Our metric downweights Joint 4 and 6 when near a wrist singularity ($|\sin(q_5)| \approx 0$), as they become redundant. We also penalize deviations in the joint sum $q_4 + q_6$ to maintain consistent orientation.
    \item \textbf{Dynamic Blend Zones}: We implement a \textit{Lock-and-Blend} strategy. Below a $3^\circ$ threshold, Joint 4 and 6 are hard-locked to their previous values. Between $3^\circ$ and $8^\circ$, a linear blend factor smoothly transitions the solution from the previous state to the new analytical goal.
    \item \textbf{Manipulability Ranking}: Solutions are ranked using the \textit{Yoshikawa Manipulability Index} ($\sqrt{\det(J J^T)}$) \cite{mathworks}. Configurations that are further away from geometric singularities (vertical arm, fully extended elbow) are prioritized.
    \item \textbf{Velocity-Aware Penalty}: The solver predicts the required joint velocity ($\dot{q} = \Delta q / \Delta t$). Solutions that would require velocities exceeding the motor's physical limits are heavily penalized to avoid physical tripping.
\end{itemize}

\subsection{Role in the Control Loop}

It is important to note that this \textbf{Analytical Inverse Kinematics} solver \cite{EAIK} is primarily used for \textbf{simulation and global initialization}. Because it is solved algebraically at a discrete pose, it is not inherently continuous. In the real-time control system, it serves as a \textbf{Seeder} for the \textbf{Differential QP Controller} (described in Section 4.3). The analytical solver provides a globally valid starting point, while the QP-based Jacobian solver ensures perfectly smooth, continuous joint trajectories during execution.

\section{Differential IK via Quadratic Programming: A Constraint-Aware Framework}

\subsection*{Executive Summary}
This report details our \textbf{Differential QP Controller}, which hybridizes analytical seeding with a numerical Quadratic Programming (QP) solver. By integrating \textbf{Selectively Damped Least Squares (SDLS)} and strict physical constraints via OSQP, the controller ensures robust, singularity-aware motion that overcomes the limitations of traditional numerical methods.

\subsection{Introduction and Problem Formulation}

\subsubsection{The Kinematic Control Challenge in Modern Robotics}
Inverse Kinematics (IK) constitutes the foundational layer of robotic manipulation, serving as the critical mathematical bridge between high-level task planning in Cartesian space and the low-level joint servo control required by actuators. The problem is formally defined as finding a joint configuration vector $\mathbf{q} \in \mathbb{R}^n$ that satisfies the non-linear mapping $\mathbf{x}_{des} = f(\mathbf{q})$, where $\mathbf{x}_{des} \in SE(3)$ represents the desired end-effector pose and $f: \mathbb{R}^n \rightarrow SE(3)$ is the forward kinematics function.

While this formulation appears straightforward, practical implementation in industrial and collaborative environments introduces significant complexity. The function $f(\mathbf{q})$ is highly non-linear, involving trigonometric compositions that result in non-convex solution spaces. Redundant manipulators possess an infinite set of solutions known as the self-motion manifold. Conversely, non-redundant manipulators may have multiple discrete geometric solutions (branches), such as "elbow-up" or "elbow-down" configurations.

\subsubsection{Limitations of Classical Numerical Solvers}
Historically, the robotics community has relied on analytical and numerical solvers. Analytical solvers are fast and complete but specific to geometry and cannot easily incorporate inequality constraints. Numerical iterative methods offer generality by solving the problem at the velocity level:
\begin{equation}
    \dot{\mathbf{x}} = \mathbf{J}(\mathbf{q})\dot{\mathbf{q}}
\end{equation}
where $\mathbf{J}(\mathbf{q}) = \partial f / \partial \mathbf{q} \in \mathbb{R}^{m \times n}$ is the manipulator Jacobian. However, these classical numerical approaches suffer from three critical pathologies:
\begin{itemize}
    \item \textbf{Local Minima Entrapment}: Gradient-based solvers descend the error landscape from an initial guess. If initialized in the basin of attraction of a local minimum, the solver may converge to a state where the Cartesian error is non-zero, yet no local movement can reduce it.
    \item \textbf{Singularity Instability}: Near kinematic singularities (where $\text{rank}(\mathbf{J}) < m$), the Jacobian becomes ill-conditioned. Pseudoinverse-based controllers command infinite joint velocities, leading to dangerous "jerk" or controller divergence.
    \item \textbf{Constraint Violation}: Pure kinematic inversion ($\dot{\mathbf{q}} = \mathbf{J}^\dagger \dot{\mathbf{x}}$) is fundamentally unconstrained. It does not natively ensure that the resulting joint coordinates $\mathbf{q}$ remain within physical limits.
\end{itemize}

\subsubsection{The Optimization Paradigm: Differential QP}
Our controller addresses these limitations by reformulating the IK problem as a \textbf{Constrained Quadratic Program (QP)}. By expressing the control objective as the minimization of a quadratic cost function subject to linear inequality constraints, the controller can optimally trade off tracking error against control effort while rigorously respecting physical boundaries. 

This implementation utilizes the \textbf{OSQP (Operator Splitting Quadratic Program)} solver, a numerical engine tailored for sparse, convex problems. Crucially, the controller augments this optimization core with a \textbf{Hybrid Architecture}, utilizing an analytical solver \cite{EAIK} to seed the optimization. This combines the global topology awareness of analytical methods with the local constraint-handling capability of numerical optimization.

\subsection{Mathematical Framework and Derivations}
The efficacy of the controller rests on a rigorous mathematical formulation that translates physical robotic constraints into the language of convex optimization.

\subsubsection{Differential Kinematics and Error Dynamics}
The controller operates in a closed-loop real-time cycle (1 kHz). At each timestep $t$, the goal is to compute a joint velocity vector $\dot{\mathbf{q}}$ that minimizes the error between the current pose and the target pose.

\paragraph{Task-Space Error Formulation}
The translational error $\mathbf{e}_p$ is the linear difference: $\mathbf{e}_p = \mathbf{p}_{target} - \mathbf{p}_{current}$. The rotational error $\mathbf{e}_o$ utilizes unit quaternions $\mathbf{Q} = [w, x, y, z]^T$. To handle the double cover of $SO(3)$, we explicitly check the inner product:
\begin{equation}
    \text{if } (\mathbf{Q}_{curr} \cdot \mathbf{Q}_{target} < 0) \implies \mathbf{Q}_{target} \leftarrow -\mathbf{Q}_{target}
\end{equation}
The orientation error is computed as: $\mathbf{e}_o = 2 \ln(\mathbf{Q}_{target} \otimes \mathbf{Q}_{curr}^{-1})$. This prevents "unwinding" jumps and ensures rotation along the geodesic path.

\paragraph{Reference Velocity Generation}
The controller employs a Proportional (P) control law in task space:
\begin{equation}
    \mathbf{v}_{ref} = K_p \begin{bmatrix} \mathbf{e}_p \\ \mathbf{e}_o \end{bmatrix}
\end{equation}
This linearizes the tracking dynamics, treating the robot as a first-order kinematic system.

\subsection{Differential QP-Based Inverse Kinematics (OSQP Formulation)}

\subsubsection{1. Optimization problem being solved}
At every control cycle, the solver computes a joint velocity command $\dot{\mathbf{q}} \in \mathbb{R}^n$ that best tracks a desired Cartesian velocity while respecting joint limits. The problem is formulated as the following convex quadratic program:
\begin{align}
    \min_{\dot{\mathbf{q}}} \quad & \frac{1}{2} || \mathbf{J}(\mathbf{q})\dot{\mathbf{q}} - \mathbf{v}_{ref} ||_{\mathbf{W}}^2 + \frac{1}{2} \dot{\mathbf{q}}^T \mathbf{\Lambda} \dot{\mathbf{q}} \\
    \text{s.t.} \quad & \dot{\mathbf{q}}_{min} \leq \dot{\mathbf{q}} \leq \dot{\mathbf{q}}_{max}
\end{align}
Where:
\begin{itemize}
    \item $\mathbf{J} \in \mathbb{R}^{6 \times n}$ is the geometric Jacobian.
    \item $\mathbf{v}_{ref} = K_p \mathbf{e}$ is the desired Cartesian velocity.
    \item $\mathbf{W}$ is a task-space weighting matrix.
    \item $\mathbf{\Lambda}$ is an adaptive SDLS damping matrix.
    \item Constraints enforce joint velocity and joint-limit damping bounds.
\end{itemize}

\subsubsection{2. Mapping to standard QP form (OSQP)}
OSQP solves problems of the form:
\begin{align}
    \min_{x} \quad & \frac{1}{2} x^T P x + q^T x \\
    \text{s.t.} \quad & l \leq A x \leq u
\end{align}
where $x \in \mathbf{R}^n$ is the optimization variable and $P \in \mathbf{S}^n_+$ a positive semidefinite matrix \cite{osqp}.

\subsubsection{3. Objective function mapping}
\paragraph{3.1 Quadratic term (Hessian)}
Expanding the least-squares objective:
\begin{equation}
    || \mathbf{J}\dot{\mathbf{q}} - \mathbf{v}_{ref} ||_{\mathbf{W}}^2 = \dot{\mathbf{q}}^T \mathbf{J}^T \mathbf{W} \mathbf{J} \dot{\mathbf{q}} - 2 \mathbf{v}_{ref}^T \mathbf{W} \mathbf{J} \dot{\mathbf{q}} + \text{const}
\end{equation}
Thus, the Hessian is defined as: $\mathbf{P} = \mathbf{J}^T \mathbf{W} \mathbf{J} + \mathbf{\Lambda}$. In practice, a small $\epsilon\mathbf{I}$ is added for numerical positive definiteness.
\begin{itemize}
    \item \textbf{Code mapping}:
\begin{lstlisting}[language=C++]
P_dense = J.transpose() * W_diag * J + Lambda;
P_dense += 1e-6 * Eigen::MatrixXd::Identity(num_joints_, num_joints_);
\end{lstlisting}
\end{itemize}

\paragraph{3.2 Linear term (gradient)}
The linear term of the QP is derived as: $\mathbf{q} = -\mathbf{J}^T \mathbf{W} \mathbf{v}_{ref}$.
\begin{itemize}
    \item \textbf{Code mapping}:
\begin{lstlisting}[language=C++]
q_grad_ = -J.transpose() * W_diag * v_ref;
\end{lstlisting}
\end{itemize}

\subsubsection{4. Constraints mapping}
\paragraph{4.1 Constraint matrix}
Only box constraints are enforced: $\dot{\mathbf{q}}_{min} \leq \dot{\mathbf{q}} \leq \dot{\mathbf{q}}_{max}$. This is implemented via an identity constraint matrix $\mathbf{A} = \mathbf{I}_{n \times n}$.
\begin{itemize}
    \item \textbf{Code mapping}:
\begin{lstlisting}[language=C++]
A_sparse_.setIdentity();
\end{lstlisting}
\end{itemize}

\paragraph{4.2 Velocity Dampers for Joint Constraints}
An implementation detail is the use of \textbf{Velocity Dampers} (also known as potential field limits or control barrier functions at the velocity level) to enforce position limits. This technique converts order-zero constraints (position) into order-one constraints (velocity), making them compatible with the differential QP formulation.

For a joint $i$ with position limits $[q_{min}^i, q_{max}^i]$ and physical velocity limits $[-v_{max}^i, v_{max}^i]$, the admissible velocity interval $[\dot{q}_{lower}^i, \dot{q}_{upper}^i]$ is dynamically adjusted based on the proximity to the limits.

The upper velocity bound is defined as:
\begin{equation}
    \dot{q}_{upper}^i(t) = \min \left( v_{max}^i, \quad \xi \frac{q_{max}^i - q_i(t)}{\Delta t} \right)
\end{equation}

The lower velocity bound is defined as:
\begin{equation}
    \dot{q}_{lower}^i(t) = \max \left( -v_{max}^i, \quad \xi \frac{q_{min}^i - q_i(t)}{\Delta t} \right)
\end{equation}
where $\xi$ is the \texttt{velocity\_damper\_gain\_} (typically $\xi \in [0.1, 1.0]$).

This formulation acts as a \textbf{"soft wall"}:
\begin{itemize}
    \item \textbf{Far from limit}: The term $\xi \frac{d_{limit}}{\Delta t}$ is large, so the bound is simply the physical motor limit $v_{max}$.
    \item \textbf{Approaching limit}: As the distance to the limit approaches zero, the allowable velocity linearly decreases, forcing the robot to decelerate smoothly.
    \item \textbf{At limit}: The velocity bound becomes zero (or negative), strictly preventing any motion that would violate the limit while permitting motion away from it.
\end{itemize}

These dynamic bounds are fed directly into the QP constraint vectors $l$ and $u$ ($l_{eff}$ and $u_{eff}$ in the code), ensuring that the optimization result is always \textbf{"viable"}---meaning a valid future trajectory exists.

\begin{table}[H]
\centering
\begin{tabular}{|l|l|l|}
\hline
\textbf{Constraint Type} & \textbf{Physical Meaning} & \textbf{Mathematical Implementation} \\ \hline
Box Constraint & Actuator Speed Limits & $\dot{q} \in [-v_{max}, v_{max}]$ \\ \hline
Barrier Constraint & Joint Position Limits & $\dot{q} \le \xi (q_{max} - q) / \Delta t$ \\ \hline
Optimization & Task Tracking & $\min || \mathbf{J}\dot{\mathbf{q}} - \mathbf{v}_{ref} ||^2$ \\ \hline
\end{tabular}
\end{table}

\begin{itemize}
    \item \textbf{Code mapping}:
\begin{lstlisting}[language=C++]
u_eff_(i) = vel_upper;
l_eff_(i) = -vel_lower;
\end{lstlisting}
\end{itemize}

\subsubsection{5. Selectively Damped Least Squares (SDLS)}
To avoid over-damping well-conditioned directions, damping is applied per singular mode \cite{buss}:
\begin{equation}
    \mathbf{\Lambda} = \sum_{i} \lambda_i^2 \mathbf{v}_i \mathbf{v}_i^T
\end{equation}
Where the per-mode damping $\lambda_i$ follows a quadratic ramp:
\begin{equation}
    \lambda_i = 
    \begin{cases} 
    \lambda_{max}(1 - \sigma_i / \sigma_{th})^2 & \text{if } \sigma_i < \sigma_{th} \\
    0 & \text{otherwise}
    \end{cases}
\end{equation}
\begin{itemize}
    \item \textbf{Code mapping}:
\begin{lstlisting}[language=C++]
Lambda += (lambda_i * lambda_i) * V.col(i) * V.col(i).transpose();
\end{lstlisting}
\end{itemize}
This preserves accuracy in non-singular directions while stabilizing the controller near rank-deficiencies.

\subsubsection{6. Final solved QP (summary)}
At each control step, OSQP solves the integrated objective:
\begin{align}
    \min_{\dot{\mathbf{q}}} \quad & \frac{1}{2} \dot{\mathbf{q}}^T (\mathbf{J}^T \mathbf{W} \mathbf{J} + \mathbf{\Lambda}) \dot{\mathbf{q}} - (\mathbf{J}^T \mathbf{W} \mathbf{v}_{ref})^T \dot{\mathbf{q}} \\
    \text{s.t.} \quad & \dot{\mathbf{q}}_{min} \leq \dot{\mathbf{q}} \leq \dot{\mathbf{q}}_{max}
\end{align}

\subsection{Hybrid Architecture: Topology and Global Awareness}
Behind the optimization core, the controller implements a Motion Lookahead and Hysteresis mechanism to navigate the robot's discrete configuration space.

\subsubsection{Predictive Motion Lookahead}
Instead of reacting only to the current error, the controller extrapolates the current trajectory to predict the robot's pose in the near future:
\begin{equation}
    \mathbf{p}_{lookahead} = \mathbf{p}_{current} + \frac{\mathbf{e}_{pos}}{||\mathbf{e}_{pos}||} \cdot \min(d_{lookahead}, ||\mathbf{e}_{pos}||)
\end{equation}
The analytical IK is solved for this future pose. This effectively asks: "If we continue moving in this direction, will we need to flip the elbow or wrist?" If the \texttt{detectBranch} function identifies that the future pose requires a different configuration branch, the controller prepares to switch. This "proto-MPC" behavior allows the robot to anticipate kinematic bifurcations rather than stumbling into them blindly.

\subsubsection{Hysteresis-Based Branch Switching}
To prevent "chattering"---the rapid, unstable oscillation between configuration branches when near a workspace boundary---the controller implements a hysteresis filter. A switch is only permitted if the cost benefit of switching exceeds a predefined threshold:
\begin{equation}
    \text{Cost}_{switch} < \text{Cost}_{stay} - \tau_{hysteresis}
\end{equation}
The cost function \texttt{computeBranchCost} penalizes joint distance and manipulability loss:
\begin{equation}
    \text{Cost}(q) = \sum (q_i - q_{current,i})^2 + \frac{1}{|\sin(q_{wrist})| + \epsilon}
\end{equation}
This logic ensures that the robot remains in its current valid configuration until the alternative becomes significantly better, mimicking the stability of biological motor control.

\subsection{Implementation and Performance Evaluation}
The system is implemented in C++ using the Eigen library and OSQP. We utilize \textbf{Warm-Starting} (initializing with the previous solution) to reduce solver iterations to $\sim 3-5$ per cycle, enabling $1\,$kHz performance.

We evaluate performance through:
\begin{itemize}
    \item \textbf{Singularity Transit}: Verifying stable velocity norms and graceful tracking degradation as $\sigma_{min} \to 0$.
    \item \textbf{Elbow Flip Testing}: Confirming 100\% reachability in configuration-switching scenarios where standard local solvers fail.
\end{itemize}

\section{Visualization and Control Interface}

The robot is operated via a custom graphical user interface developed using the \textbf{Qt/QML} framework and C++. This application acts as the high-level controller, bridging the kinematic solvers with the real-time hardware telemetry.

\begin{figure}[H]
    \centering
    
    \caption{The Primary Control Interface showing the 3D robot model and control panels.}
    \label{fig:viz_main}
\end{figure}

\subsection{Connection and Initialization}

The software includes an automated hardware detection system. Upon startup, it scans the available serial ports to identify the custom MCU. Once detected, the system prompts the user to connect:

\begin{figure}[H]
    \centering
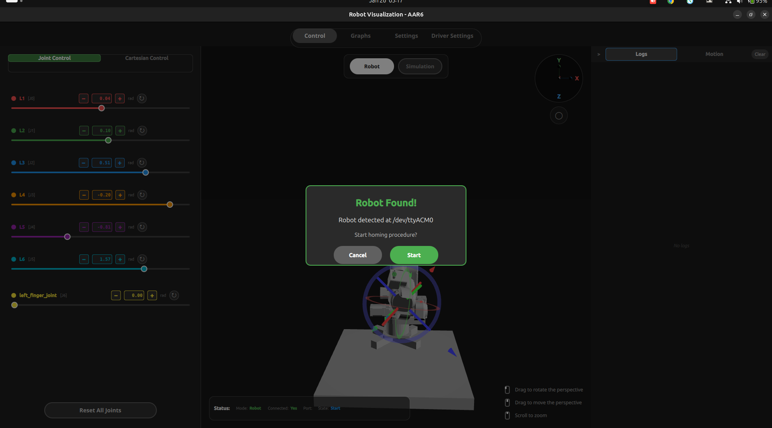
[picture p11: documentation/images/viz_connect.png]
    
    \caption{The automated connection prompt and MCU detection status.}
    \label{fig:viz_connect}
\end{figure}

Upon successful connection, the software initiates a \textbf{Homing Sequence}. This ensures that the physical robot's joint positions are synchronized with the internal kinematic model, establishing a verified zero-frame for all subsequent motions.

\subsection{Control Modes and Input Methods}

The interface utilizes a Model-View-Controller (MVC) architecture where the \textbf{QML} layer handles the interactive 3D rendering and 2D controls, while the \textbf{C++} backend manages the thread-safe communication and IK computation.

Users can control the robot through several input modalities:

\begin{enumerate}
    \item \textbf{Cartesian Drag (3D Gizmo)}: 
    An interactive 3D transform gizmo is attached to the end-effector in the 3D view. Users can drag this gizmo to move the robot in real-time. The software solves the Differential QP-IK at high frequency, streaming smooth trajectories to the MCU.
    
    \begin{figure}[H]
        \centering
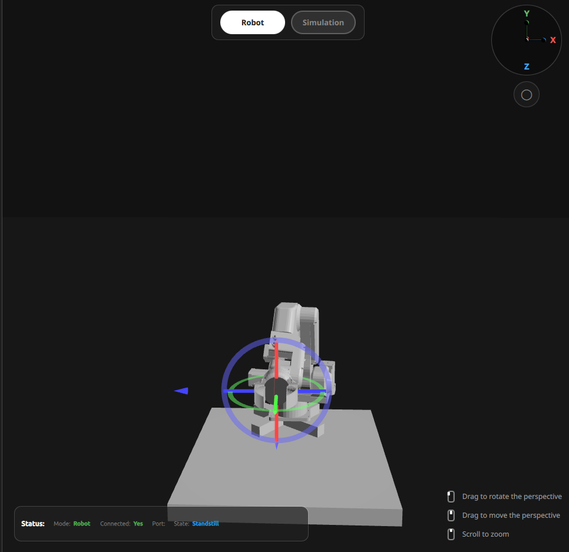
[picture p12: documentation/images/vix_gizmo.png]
        
        \caption{Interactive 3D Gizmo for real-time Cartesian manipulation.}
        \label{fig:viz_gizmo}
    \end{figure}

    \item \textbf{Cartesian Command Panel}: 
    For precise numerical input, the Cartesian panel allows users to specify exact target coordinates and orientations. This is particularly useful for tasks requiring sub-millimeter precision that are difficult to achieve through 3D dragging alone.

    \begin{figure}[H]
        \centering
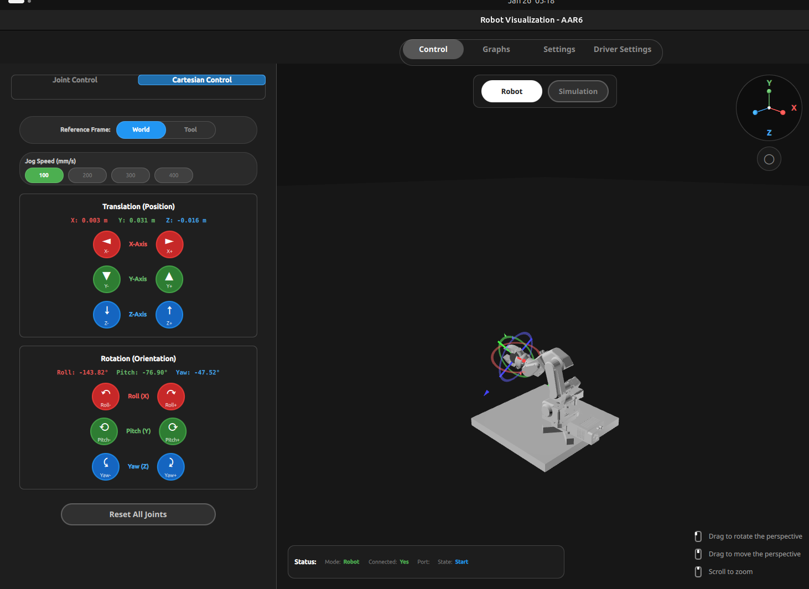
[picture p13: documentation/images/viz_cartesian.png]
        
        \caption{Cartesian command and target coordinate panel.}
        \label{fig:viz_cartesian}
    \end{figure}

    \item \textbf{Joint-Space Sliders}: 
    Individual sliders permit direct manipulation of each joint angle (q1-q6). This is useful for manual configuration, diagnostic testing, and verification of individual actuator health.

    \begin{figure}[H]
        \centering
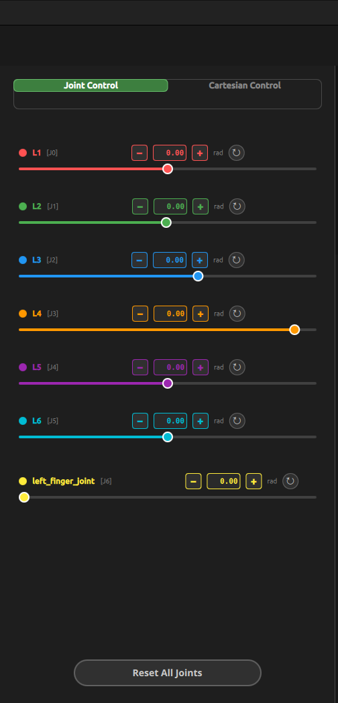
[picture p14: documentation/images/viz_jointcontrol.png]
        
        \caption{Joint-space control interface (Sliders) and Cartesian command panel.}
        \label{fig:viz_controls}
    \end{figure}

    \item \textbf{Motion Planning and Waypoints}: 
    The software features a dedicated \textit{Motion Controller} and \textit{Panner}. Users can add specific pose waypoints to a sequence and play them back. The system interpolates between these points using the internal S-Curve engine to ensure smooth transitions.

    \begin{figure}[H]
        \centering
        \begin{minipage}{0.48\textwidth}
            \centering
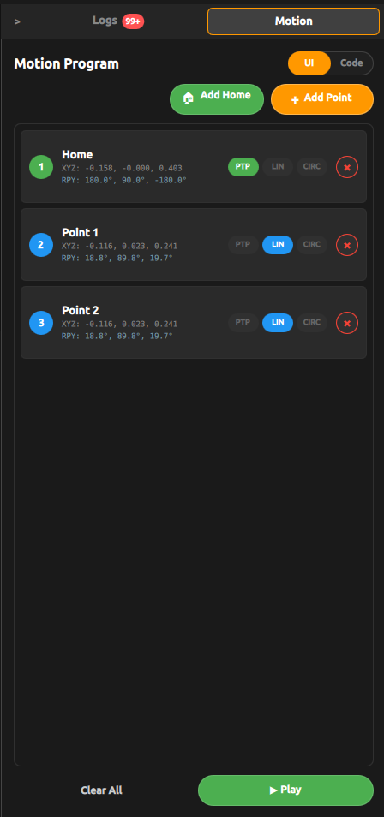
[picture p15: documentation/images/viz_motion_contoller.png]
            
            \caption{Motion waypoint sequence planner.}
        \end{minipage}\hfill
        \begin{minipage}{0.48\textwidth}
            \centering
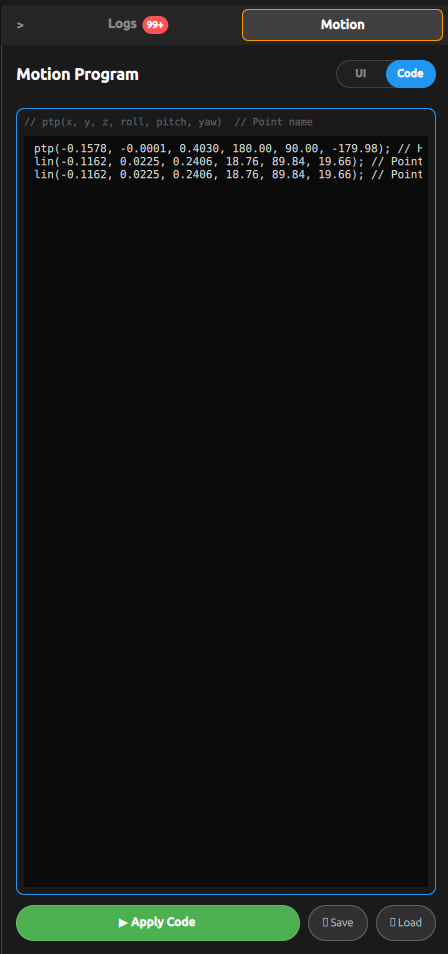
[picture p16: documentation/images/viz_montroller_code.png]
            
            \caption{Integrated scripting and code interface.}
        \end{minipage}
    \end{figure}

    \item \textbf{Scripting Interface}: 
    For complex task automation, users can write code directly within the interface to execute logic-based motion sequences, integrating sensor feedback or timed events.
\end{enumerate}

\subsection{System Telemetry and Visualization}

The 3D visualization is a mirror of the physical robot. As joint positions are streamed back from the MCU at 100\,Hz, the 3D model is updated via the Forward Kinematics engine, providing the user with an accurate representation of the robot's current state.

\begin{figure}[H]
    \centering
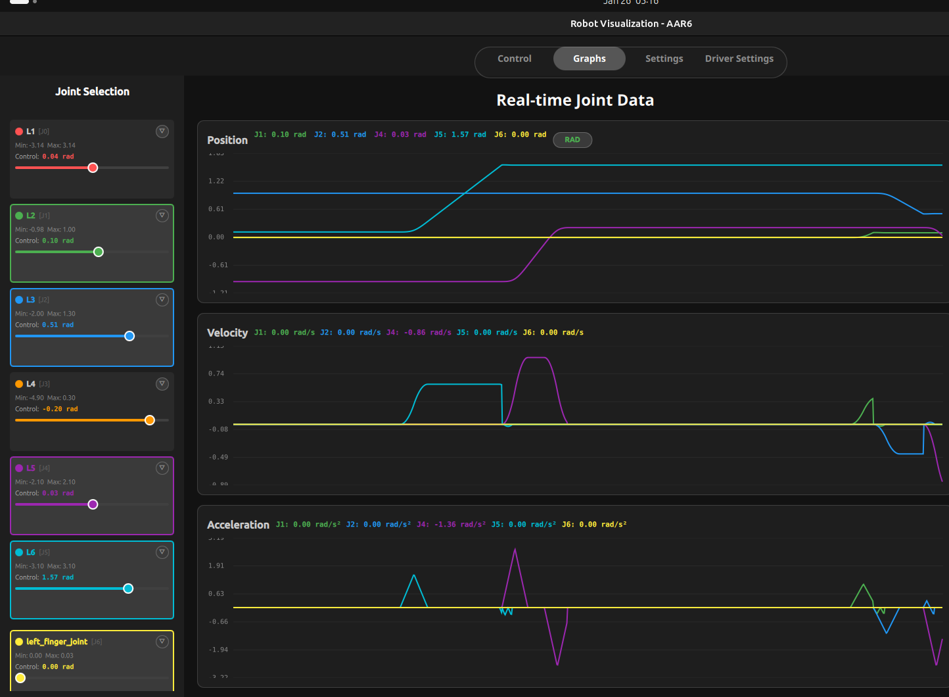
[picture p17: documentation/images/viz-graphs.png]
    
    \caption{Real-time joint velocity and acceleration telemetry graphs.}
    \label{fig:viz_graphs}
\end{figure}

\section{Project Status: Limitations and Future Roadmap}

The current implementation provides a high-fidelity 6-DOF control system; however, technical constraints across hardware, control logic, and software frameworks define the roadmap for future development.

\subsection{Hardware and Connectivity}
\begin{itemize}
    \item \textbf{Actuator Driver Status (J3)}: The system is currently missing two primary drivers. A temporary "jerry-rigged" driver is currently in use for Joint 3 (J3); however, it is prone to thermal shutdowns due to temperature regulation issues and must be replaced. This failure mode was precipitated by high Back-EMF from J3, which destroyed two previous drivers. A high-quality, high-EMF-rated driver is required for stable long-term operation (\href{https://biqu.equipment/products/bigtreetech-tmc5160-v1-0-driver-spi-mode-silent-high-precision-stepstick-stepper-motor-driver-with-heatsink-for-skr-v1-3-gen-v1-4-rep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}{TMC5160 Product Page}).
    \item \textbf{End-Effector (Gripper) Status}: The gripper is currently disconnected from the control loop. This is due to a combination of time constraints and the aforementioned driver failures, leaving insufficient functional drivers for complete integration.
    \item \textbf{Payload and Mass Distribution}: The NEMA-style stepper motor used for the gripper adds approximately 300\,g of dead weight at the end of the arm. This significantly reduces the effective payload capacity and increases the inertial load during high-acceleration maneuvers. 
    \item \textbf{Position Encoders (AS5600)}: The AS5600 magnetic encoders are currently not connected to the control loop. Once integrated, these will enable \textbf{Admittance Control} and adjustable arm stiffness. This hardware capability will allow for "lead-through" programming, where the user can teach the robot new paths simply by physically moving the arm.
\end{itemize}

\subsection{Kinematic and Dynamic Control}
\begin{itemize}
    \item \textbf{Collision Awareness}: The Differential IK solver does not natively account for self-collisions or obstacle avoidance. Future work involves adding Control Barrier Function (CBF) constraints to the QP formulation.
    \item \textbf{Full Dynamics Modeling}: The system is purely kinematic. Moving to a dynamic model (implementing gravity and inertia compensation) would significantly improve performance with heavy payloads.
    \item \textbf{Hybrid Singularities}: While SDLS handles mathematical singularities, the transition between discrete configuration branches (elbow flip) remains a focus for more advanced predictive "look-ahead" optimizations.
    \item \textbf{Jerk-Limited Motion}: The current controller provides smooth trajectories but is not inherently jerk-limited. This is because it solves a memoryless velocity-level QP. Achieving full jerk limiting would require either higher-order state constraints within the QP formulation or a dedicated time-domain filter applied as a post-processing stage.
\end{itemize}

\subsection{Software and Integration}
\begin{itemize}
    \item \textbf{Automatic Hardware Detection}: The current automatic MCU detection system is known to fail intermittently. Manual port selection or retry logic is sometimes required to establish a stable communication link.
    \item \textbf{Control Loop Performance}: The high-level control loop, while stable, has several identified paths for optimization. Reducing computational overhead in the IK solver and improving thread synchronization would enable higher streaming frequencies and lower control latency.
    \item \textbf{Code-Base Modularity}: Continual refactoring to separate the core kinematic solvers from the GUI logic will enhance the portability of the controller to other robotic platforms.
\end{itemize}

\begin{thebibliography}{9}
    \bibitem{buss} Buss, S. R., \& Kim, J. S. (2005). Selectively Damped Least Squares for Inverse Kinematics. \url{https://mathweb.ucsd.edu/~sbuss/ResearchWeb/ikmethods/SdlsPaper.pdf}
    \bibitem{ieee_sdls} Buss, S. R., \& Kim, J. S. (2005). A Selectively Damped Least Squares Method for Inverse Kinematics. \textit{IEEE/ASME Transactions on Mechatronics}, 10(3), 312--320. \url{https://ieeexplore.ieee.org/document/9757150}
    \bibitem{faverjon} Faverjon, B., \& Tournassoud, P. (1987). A local based approach for path planning of manipulators with a high number of degrees of freedom.
    \bibitem{mathworks} MathWorks. Manipulability index. Robotics System Toolbox. \url{https://www.mathworks.com/help/robotics/ref/manipulabilityindex.html}
    \bibitem{osqp} Stellato, B., Banjac, G., Goulart, P., Bemporad, A., \& Boyd, S. (2020). OSQP: an operator splitting solver for quadratic programs. \textit{Mathematical Programming Computation}, 12(4), 637--672.
    \bibitem{EAIK} Ostermeier, D., Külz, J., \& Althoff, M. (2025). Automatic Geometric Decomposition for Analytical Inverse Kinematics. \textit{IEEE Robotics and Automation Letters}, 10(10), 9964--9971.
    \bibitem{tmc5160_prod} BigTreeTech. TMC5160-V1.0 Stepper Motor Driver. Product Page. \url{https://biqu.equipment/products/bigtreetech-tmc5160-v1-0-driver-spi-mode-silent-high-precision-stepstick-stepper-motor-driver-with-heatsink-for-skr-v1-3-gen-v1-4-rep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}
\end{thebibliography}

%% ========================================
%% APPENDIX
%% ========================================

\appendix

\chapter{Source Code Repositories}
The source code for the various components of this project is hosted on GitHub.
\begin{itemize}
    \item \textbf{Control Board Design}: \url{https://github.com/Amigo10101/AAR6/tree/main/control_board}
    \item \textbf{Robot Microcontroller Firmware}: \url{https://github.com/Amigo10101/AAR6/tree/main/mcu_firmware}
    \item \textbf{Robot Controller Software}: \url{https://github.com/Amigo10101/AAR6/tree/main/urdf_standalone}
\end{itemize}

\end{document}

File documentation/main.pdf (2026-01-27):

# Design and Implementation of a 6-DOF Robotic Manipulator

# with Singularity-Robust Motion Control

# Project Report

### Anwesh Rijal (16940572) Austin Mathew Palamoottil (26044014)

### Hochschule Ravensburg-Weingarten University

### January 2026

# Contents

1 Introduction | 3
2 Hardware | 5
3 MCU Firmware | 13

4 Motion Control Software and Kinematics | 17

4.2 Differential IK via Quadratic Programming: A Constraint-Aware Framework 23

4.2.3 | Differential QP-Based Inverse Kinematics (OSQP Formulation) . . 25
A Source Code Repositories | 36

# Chapter 1

# Introduction

## 1.1 Project Background

This project involves the development of a 6-DOF robotic arm control system, including custom firmware and host software. The mechanical design is based on the open-source PAROL6 desktop robot arm developed by Source Robotics.

### 1.1.1 Base Design Attribution

The robot hardware design used in this project is derived from:

- PAROL6 Desktop Robot Arm by Source Robotics
- Design by Petar Crnjak (https://github.com/PCrnjak)
- Documentation: https://source-robotics.github.io/PAROL-docs/
- Hardware: https://github.com/PCrnjak/PAROL6-Desktop-robot-arm

This project extends the base PAROL6 design with custom firmware and software implementations.

## 1.2 Project Objectives

The primary objectives of this project are:

1. Build a Fully Functional 6-DOF Robotic Arm: Assemble and integrate the mechanical structure, stepper motors, control electronics, and end effector into a working desktop manipulator.
2. Develop Stable Motion Control Software: Implement a robust inverse kinematics controller capable of smooth, singularity-free motion throughout the workspace.
3. Implement Real-Time Control: Create firmware and host software that can execute motion commands with low latency and high precision.

### 1.2.1 Controller Objectives

The motion controller specifically aims to:

- Provide stable velocity-level IK using quadratic programming (QP)
- Handle kinematic singularities gracefully using adaptive damping
- Support real-time interactive control via visualization interface
- Respect joint position and velocity limits at all times

### 1.2.2 Software Architecture

The control software consists of two main components:

- MCU Firmware (STM32F446): Handles low-level motor control, step generation, S-curve motion profiles, and serial communication with the host.
- Host Software (C++/Qt): Implements kinematics computation (FK/IK), the QP-based differential controller with singularity handling, and 3D visualization for interactive control.

## 1.3 Scope

This project covers:

- Mechanical assembly of the PAROL6-based robot arm
- Custom control board with STM32F446 and TMC5160 drivers
- MCU firmware for motion execution
- Host-side kinematics and motion control software
- 3D visualization and user interface

## 1.4 Document Structure

- Chapter 2 - Hardware: Robot mechanical design, control board, electrical connections
- Chapter 3 - MCU Firmware: Motor control, S-curve profiles, communication
- Chapter 4 - Motion Control Software: Kinematics, QP-based differential controller, visualization
- Appendices: Pinout, DH parameters, joint limits

# Chapter 2

# Hardware

This chapter describes the physical hardware of the our robotic arm system.

## 2.1 The Robot

### 2.1.1 Overview

Our robot is based on the PAROL6 open-source robot arm design by Source Robotics. It is a 6 degrees of freedom (6-DOF) desktop robotic arm designed for education, research, and light industrial applications. The robot features an articulated arm configuration with all revolute joints, providing full spatial manipulation capability.
The mechanical design, including 3D printed parts and assembly, follows the original PAROL6 specifications with modifications for this project.
Parameter | Value
Degrees of Freedom Weight Power Consumption Material Communication | 6 rotating joints 5.5 kg 40 W 3D printed ABS plastic USB

Table 2.1: Robot Specifications

### 2.1.2 Mechanical Structure

The robot is constructed primarily from 3D printed ABS plastic. ABS provides good mechanical strength and thermal resistance for this application.

Joint Configuration

Joint | Function | Range | Reduction
J1 J2 J3 J4 J5 J6 | Base rotation Shoulder lift Elbow bend Wrist rotation Wrist pitch Tool rotation | 250° 141° 180° 212° 180° ∞ | Belt 6.4:1 Planetary 20:1 Planetary 20:1 + Belt 38:42 Belt 4:1 Belt 4:1 Planetary 10:1

Table 2.2: Joint Configuration and Reduction Ratios

Spherical Wrist Design

The robot uses a spherical wrist configuration, where the last three joint axes (J4, J5, J6) intersect at a single point called the wrist center. This design is common in industrial manipulators and simplifies inverse kinematics by decoupling position and orientation problems.

Kinematic Singularities

Singularities are configurations where the robot loses one or more degrees of freedom. For our 6-DOF spherical wrist arm, three main singularities exist:

1. Wrist Singularity: Occurs when J4 and J6 axes align (J5 = 0° or 180°)
2. Shoulder Singularity: Wrist center lies on the J1 axis
3. Elbow Singularity: Arm fully extended or folded

Near singularities, the inverse Jacobian produces very large joint velocities, causing instability. Our software mitigates this using adaptive damping techniques (see Chapter 4).

### 2.1.3 Actuators

All joints use stepper motors with the following configuration:

- Motor type: NEMA 17 / NEMA 23 stepper motors
- Steps per revolution: 200 (1.8° step angle)
- Microstepping: 32 microsteps (6400 steps/revolution)
- Drivers: TMC5160 (BigTreeTech) with StallGuard [7]
- Gearboxes: Precision planetary gearboxes and belt drives

Step Resolution

With 32 microstepping and gear reduction, the theoretical step resolution at each joint:

Joint | Resolution (rad) | Resolution (deg)
J1 J2 J3 J4 J5 J6 | 0.000153 0.000049 0.000054 0.000245 0.000245 0.000098 | 0.00879° 0.00281° 0.00311° 0.01406° 0.01406° 0.00563°

Table 2.3: Joint Step Resolution (after gear reduction)

### 2.1.4 Sensors

- Position sensing: AS5600 magnetic encoders for closed-loop position feedback
- Limit switches: Used for homing and end-of-travel protection

### 2.1.5 End Effector

The end effector is a custom-designed electric gripper based on the SSG-48 Adaptive
Electric Gripper by Source Robotics (https://github.com/PCrnjak/SSG-48-adaptive-electric-gripper).

Gripper Redesign

The original SSG-48 design was heavily modified for this project:

- Actuation: Replaced original motor with a stepper motor for precise position control
- Position Feedback: Added AS5600 magnetic encoder for closed-loop gripper position sensing
- Control: Integrated with the main control system for coordinated motion

Gripper Specifications

Parameter | Value
Actuation Position Sensor Control Mode Base Design | Stepper motor AS5600 magnetic encoder Closed-loop position SSG-48 (Source Robotics)

Table 2.4: Gripper Specifications

## 2.2 Control Board

### 2.2.1 Overview

A custom PCB was designed to integrate all control electronics for the robot. The board serves as the central interface between the STM32 microcontroller and all motor drivers, sensors, and power systems.


Figure 2.1: Control Board PCB Layout


Figure 2.2: Control Board 3D View

Key Features

- MCU Interface: Socket for STM32 Nucleo development board
- Motor Drivers: 7× TMC5160 BigTreeTech driver slots (6 robot joints + 1 gripper)
- Motor Outputs: Connectors for all stepper motors
- Limit Switches: Input connectors for all joint limit switches
- Power Interface: Motor power input and distribution

### 2.2.2 Microcontroller

The control board uses an STM32 Nucleo development board as the main processor:

- Plugs into dedicated socket on the control board
- Provides all GPIO, timer, and communication interfaces
- USB connection for host communication
- Firmware development and debugging via ST-Link

### 2.2.3 Motor Drivers

The board accommodates 7 TMC5160 BigTreeTech stepper drivers:

Slot | Function | Motor
1 2 3 4 5 6 7 | Joint 1 Joint 2 Joint 3 Joint 4 Joint 5 Joint 6 Gripper | Base rotation Shoulder Elbow Wrist 1 Wrist 2 Wrist 3 End effector

Table 2.5: Motor Driver Assignments

### 2.2.4 Power System

- Motor Power: Direct connection for motor supply voltage
- Logic Power: Regulated from motor supply or USB

### 2.2.5 Connectors

- Motor outputs: 7× stepper motor connectors (4-pin)
- Limit switches: Input connectors for each joint
- Encoder inputs: For AS5600 position feedback
- Power input: Main power connector

## 2.3 Electrical Connections

This section presents the schematic diagrams for the main electrical subsystems.

### 2.3.1 MCU Connections

The STM32 Nucleo board interfaces with all other subsystems:

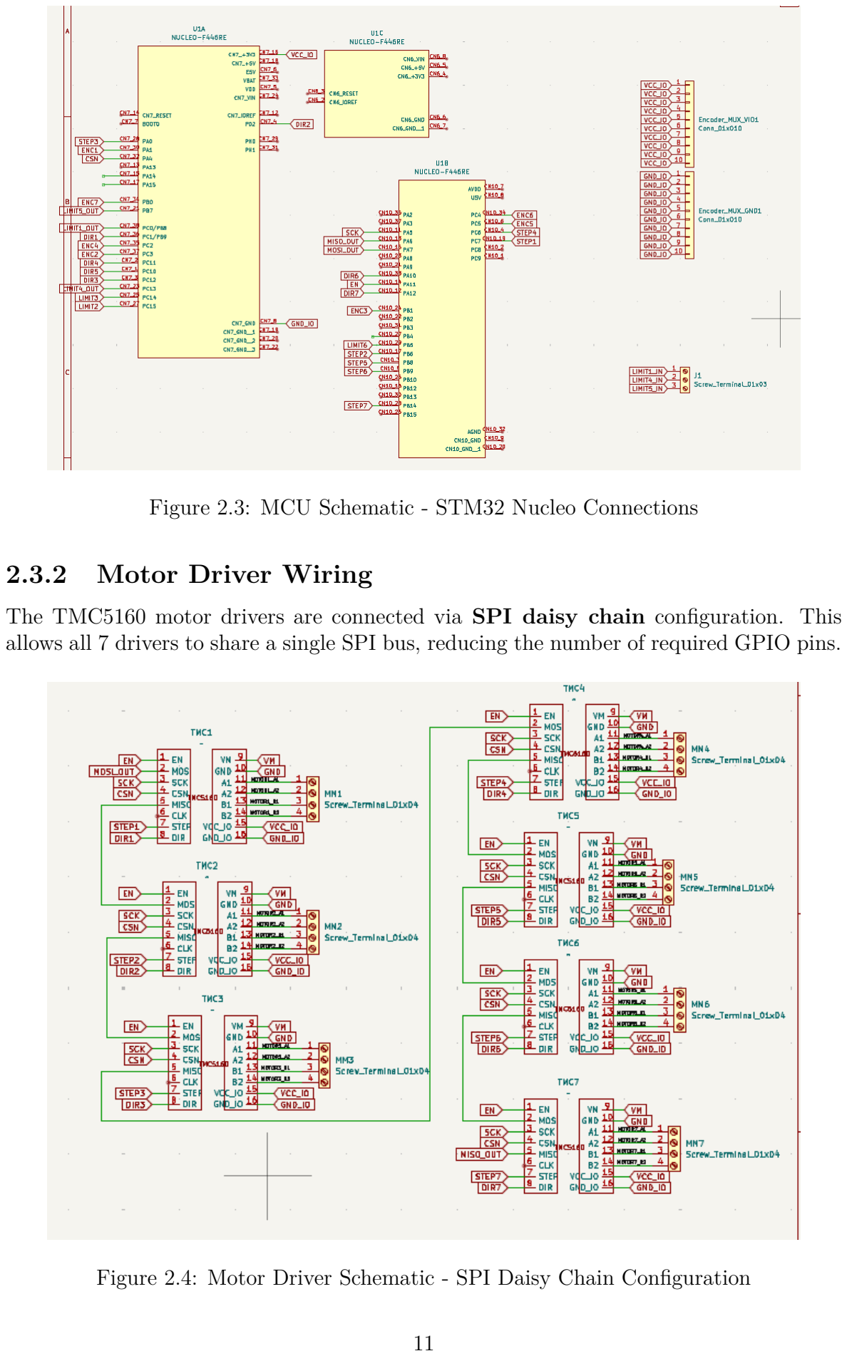
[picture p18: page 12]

Figure 2.3: MCU Schematic - STM32 Nucleo Connections

### 2.3.2 Motor Driver Wiring

The TMC5160 motor drivers are connected via SPI daisy chain configuration. This allows all 7 drivers to share a single SPI bus, reducing the number of required GPIO pins.

Figure 2.4: Motor Driver Schematic - SPI Daisy Chain Configuration

SPI Daisy Chain

In daisy chain mode:

- All drivers share common SCK (clock) and CS (chip select) lines
- Data passes from SDO of one driver to SDI of the next
- Single SPI transaction addresses all 7 drivers sequentially
- Reduces wiring complexity and MCU pin usage

### 2.3.3 Limit Switch Wiring

Each joint has a limit switch for homing and end-of-travel protection:

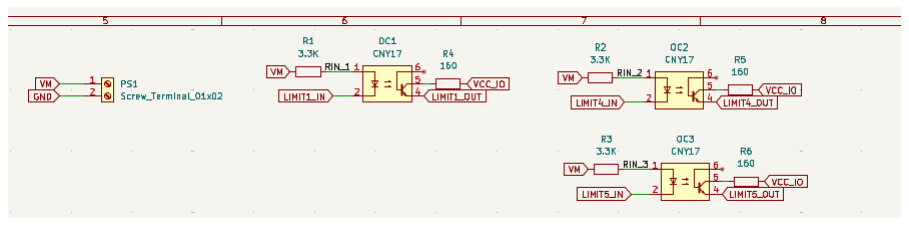
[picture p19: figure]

Figure 2.5: Limit Switch Schematic

# Chapter 3

# MCU Firmware

This chapter describes the firmware running on the STM32 Nucleo microcontroller.

## 3.1 Firmware Overview

The MCU firmware is responsible for real-time motor control, sensor reading, and communication with the host. It uses FreeRTOS for task management.

### 3.1.1 System Architecture


Figure 3.1: System Architecture and Data Flow across Host PC, MCU, and Hardware

### 3.1.2 RTOS Tasks

The firmware utilizes a hybrid architecture combining high-frequency interrupts for motion control with RTOS tasks for communication and low-priority monitoring:

Component | Priority/Rate | Function
TIM7 ISR PWM Step ISR UART Task Sensor Task | 20 kHz Event-based High Low | S-Curve engine update, PWM frequency modulation Real-time position tracking, target-reached stopping DMA-based telemetry streaming and command parsing PCA9548A MUX detection and health monitoring

Table 3.1: Real-Time Software Components

## 3.2 Motor Control

### 3.2.1 TMC5160 Driver Interface

The firmware communicates with TMC5160 drivers via SPI:

- Daisy chain configuration for all 7 drivers
- Register access for current, velocity, and position control
- StallGuard feedback for sensorless homing

### 3.2.2 Step Generation

Motor steps are generated using hardware timers:

- Timer-based step pulse generation
- Velocity and acceleration limiting
- Smooth start/stop transitions

The firmware implements a high-performance 7-segment S-Curve motion profile to ensure continuous acceleration and minimize mechanical vibrations. Unlike standard trapezoidal profiles, the S-Curve limits the third derivative of position (jerk), preventing the "infinite jerk" spikes that lead to motor skipping and structural resonance.

### 3.2.3 Mathematical Foundation

The motion profile is governed by the constant jerk J, which is the rate of change of acceleration a. The kinematic states are derived through successive integration:

a(t) = a0 +

Z t

0

J(τ )dτ | (3.1)

v(t) = v0 +

Z t

0

a(τ )dτ = v0 + a0t +

1
2

J t²
| (3.2)

s(t) = s0 +

Z t

0

v(τ )dτ = s0 + v0t +

1
2

a0t

2 +

1
6

J t³
| (3.3)

### 3.2.4 The 7-Segment Profile

A full point-to-point motion consists of seven distinct phases:

1. Jerk-up: Jerk is constant (+Jmax), acceleration increases linearly.
2. Constant Accel: Jerk is zero, acceleration is constant (amax).
3. Jerk-down: Jerk is constant (−Jmax), acceleration decreases to zero as velocity reaches the maximum setpoint.
4. Constant Velocity: Jerk and acceleration are zero.
5. Jerk-down: Jerk is constant (−Jmax), acceleration linearly decreases (deceleration increases).
6. Constant Decel: Jerk is zero, deceleration is constant (−amax).
7. Jerk-up: Jerk is constant (+Jmax), deceleration returns to zero as the target position is reached.

### 3.2.5 Implementation Strategy

The firmware executes this engine within the TIM7 ISR at 20 kHz. This high frequency (50 µs ticks) allows for quasi-continuous updates of the output PWM frequency, ensuring the motor follows the ideal curve with negligible quantization error.

Adaptive Deceleration

Because the MCU must handle dynamic target updates and external interruptions, the engine does not simply "blindly" run a pre-calculated curve. Instead, it performs a deceleration check every 1 ms:

- It continuously calculates the stopping distance required to reach zero velocity from the current speed using maximum jerk/decel limits.
- When the remaining distance to the target is less than or equal to the stopping distance, it triggers the transition from constant velocity to the deceleration phases (Phase 5).
- Overshoot Correction: In the final pulses (Phase 7), any remaining floating-point error is compensated by an adaptive "dist-remove-per-cycle" calculation, guaranteeing that the final pulse lands exactly on the integer step target.

## 3.3 Communication Protocol

Communication with the host software is implemented over a high-speed USB-CDC serial link (baud rate 921,600). The protocol uses a robust binary framing to ensure data integrity and low latency.

### 3.3.1 Framing Structure

All packets, regardless of direction, share a common header and footer structure:

- Start Frame: 0xAA 0x55 (2 bytes)
- Length: Payload size (2 bytes, Little-Endian)
- Payload: Actual data (variable length)
- Checksum: XOR sum of all payload bytes (1 byte)

### 3.3.2 Outgoing Format (MCU → PC)

The MCU streams telemetry at 100 Hz. The primary telemetry packet (Type 0x01) payload consists of:

- Joint Data: 6 joints × (Position, Velocity, Acceleration) as 32-bit floats (72 bytes total)
- Robot State: 1 byte integer (Current operational mode)

### 3.3.3 Incoming Format (PC → MCU)

The host sends control and motion commands. The payload structure varies by command type:

- State Commands: 1 byte (e.g., CMD_ESTOP, CMD_HOME)
- Motion Commands: 2 bytes (Command Type + Action) followed by 6 joints × (Position, Velocity) as 32-bit floats (50 bytes total)

# Chapter 4

# Motion Control Software and Kinematics

This chapter describes the kinematics theory and the host-side software for computation and control.

## 4.1 Kinematics Theory

Kinematics describes the motion of the robot without considering the forces that cause it. For our 6-DOF arm, we define the relationship between joint space q ∈ R

6 and task
space x ∈ SE(3).

### 4.1.1 Forward Kinematics

Forward Kinematics (FK) is the mathematical process of determining the pose (position and orientation) of the end-effector given a set of joint angles. For a 6-DOF manipulator like our arm, this involves mapping a vector of joint angles q = [q1, q2, q3, q4, q5, q6]

T
to a
homogeneous transformation matrix 0T6 ∈ SE(3).

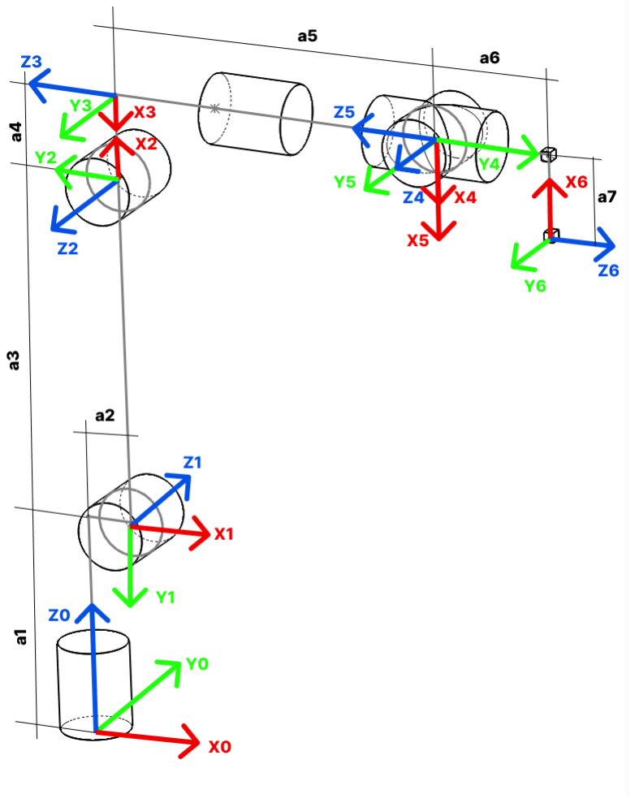
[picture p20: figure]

Figure 4.1: Robot Kinematic Diagram showing joint axes and coordinate frames

The Denavit-Hartenberg (DH) Convention

To systematically represent the relationship between adjacent links, we adopt the Standard Denavit-Hartenberg (DH) convention. This method assigns a coordinate frame to each joint and describes the transformation from frame i − 1 to frame i using four parameters:

- Joint Angle (θi): Rotation about the zi−1 axis. This is the variable component for revolute joints.
- Link Offset (di): Distance along the zi−1 axis from the origin of frame i − 1 to the common normal between zi−1 and zi

- Link Length (ai): Distance along the xi axis (the common normal) between the zi−1 and zi axes.
- Link Twist (αi): Rotation about the xi axis required to align zi−1 with zi

The individual transformation matrix i−1Ti is the result of four successive operations: Rotz(θi) → T ransz(di) → T ransx(ai) → Rotx(αi).

i−1Ti =

cos θi | − sin θi cos αi | sin θi sin αi | ai cos θi
sin θi | cos θi cos αi | − cos θi sin αi | ai sin θi
0 | sin αi | cos αi | di
0 | 0 | 0 | 1

(4.1)

Robot DH Parameters

Based on the physical dimensions of our robot arm, the following DH parameters define the kinematic chain. The base height H1, link lengths L2, L3, and wrist offsets W1, W2 are derived from the URDF model.


Figure 4.2: Physical Link Lengths


Figure 4.3: Joint Rotation Directions

Link | θi | di | ai | αi
1 2 3 4 5 6 | q1 q2 q3 q4 q5 q6 | 110.5 mm 0 mm 0 mm 176.35 mm 0 mm 52.0 mm | 23.4 mm 180.0 mm 43.5 mm 0 mm 51.0 mm 0 mm | −90◦ 180◦ 90◦ −90◦ 90◦ ◦ 0

Table 4.1: DH Parameters for the 6-DOF Robot Arm

The total transformation from the base to the end-effector is obtained by multiplying these matrices in sequence:

0Tee(q) = 0T1(q1) ·

1T2(q2) ·

2T3(q3) ·

3T4(q4) ·

4T5(q5) ·

5T6(q6) | (4.2)

End-Effector Pose Extraction

The resulting 4 × 4 homogeneous transformation matrix 0Tee contains the full pose information relative to the base frame. It is partitioned as follows:

0Tee =

"
n s a p

0 0 0 1#
=

r11 | r12 | r13 | px
r21 | r22 | r23 | py
r31 | r32 | r33 | pz
0 | 0 | 0 | 1

(4.3)

where:

- Position: The vector p = [px, py, pz]

T
represents the Cartesian coordinates of the end-effector origin.
- Orientation: The 3 × 3 submatrix R = [n, s, a] represents the rotation of the end-effector. The columns n (normal), s (sliding), and a (approach) are unit vectors defining the orientation of the final link’s axes in the base frame.

In our software, this position vector and rotation matrix are used directly for error computation in the numerical solvers and for visualization in the 3D interface.

### 4.1.2 The Jacobian Matrix

The Jacobian matrix J(q) is a fundamental operator in robotics that maps velocities from joint space to task space. For our 6-DOF manipulator, it relates the joint velocity vector q˙ ∈ R

6
to the end-effector twist ξ = [v, ω]

T ∈ R
6
:
"
v
ω
= J(q)q˙ | (4.4)

where v is the linear velocity and ω is the angular velocity of the end-effector.

Geometric Jacobian Derivation

The Jacobian is composed of six columns, J = [j1,j2, . . . ,j6], where each column represents the contribution of a single joint to the end-effector velocity. Since all joints in our robot are revolute, the i-th column is derived geometrically as:

ji =

"
zi−1 × (pee − pi−1)

zi−1

| (4.5)

where:

- zi−1 is the unit vector along the axis of rotation of joint i.
- pee is the position of the end-effector in the base frame.
- pi−1 is the position of the origin of frame i − 1 in the base frame.

The Jacobian is highly configuration-dependent. When J(q) becomes singular (loses rank), the robot loses one or more degrees of freedom in task space. This occurs when joint axes align or the arm reaches its workspace boundaries.

### 4.1.3 Singularity Handling: Selectively Damped Least Squares

To maintain stability near singularities, we utilize the Selectively Damped Least Squares (SDLS) method. Unlike standard Damped Least Squares (Tikhonov regularization) which adds a uniform penalty to all joints, SDLS specifically targets only the singular directions in the task space.
Through Singular Value Decomposition (SVD), the Jacobian is decomposed as:

J = UΣVT
(4.6)

where the columns of V are joint-space vectors. We construct a damping matrix Λ that acts only in the basis of these vectors:

Λ =

Xn

i=1

λ

2
i viv

T
i

(4.7)

The per-mode damping factor λi is computed based on the singular value σi

:

λi =

λmax
1 −

σi

σthreshold 2
if σi < σthreshold
0 | otherwise

(4.8)

This approach ensures that "healthy" directions remain precise while "singular" directions are smoothly constrained, preventing infinite joint speeds and numerical instability.

### 4.1.4 Inverse Kinematics

Inverse Kinematics (IK) is the process of finding the joint angles q that result in a desired end-effector pose. Unlike FK, IK is non-linear and can have multiple solutions, or no solution if the target is outside the workspace.

Analytical Inverse Kinematics

Analytical (closed-form) Inverse Kinematics is the process of finding joint angles q algebraically. Our robot’s architecture allows for a kinematic decoupling strategy, which divides the 6-DOF problem into two smaller, independent subproblems: a 3-DOF positional problem and a 3-DOF orientational problem.

### 1. Kinematic Decoupling (Wrist Center) The key requirement for decoupling is

that the axes of the last three joints (Joints 4, 5, and 6) intersect at a single point, known as the wrist center (Pw). Because rotational motion of the wrist does not move Pw, its position is determined solely by the first three joints.
Given a target end-effector position ptarget and its approach vector a (the z-axis of the end-effector frame), the wrist center is calculated as:
pw = ptarget − d6 · a | (4.9)

where d6 = 52.0 mm is the distance from the wrist center to the end-effector tip.

### 2. Solving for the Arm (Joints 1, 2, 3) With pw = [xw, yw, zw]

T known in the base
coordinate frame:
- Base Rotation (q1): The first joint rotates the entire arm to align with the x − y projection of the wrist center:
q1 = atan2(yw, xw) (or q1 + π for reversed base) | (4.10)
- Planar Geometry (q2, q3): Once q1 is fixed, the problem simplifies to a 2D planar linkage. We solve for q2 and q3 using the Law of Cosines based on the triangle formed by L2, L3, and the radial distance to Pw. This step yields two solutions per base configuration: Elbow Up and Elbow Down.

### 3. Solving for the Wrist (Joints 4, 5, 6) After calculating the arm joints, the

rotation matrix from the base to Joint 3, 0R3, is fully defined. To reach the target orientation Rtarget, the wrist must provide the remaining rotation 3R6:

3R6 = (⁰R3)

T
- Rtarget | (4.11)

The matrix 3R6 corresponds to a standard Z-Y-Z Euler sequence defined by the wrist joints q4, q5, q6. Equating the elements of 3R6 to the Euler rotation matrix allows us to extract the angles:

q5 = ± acos(R33) (where R33 is the bottom-right element) | (4.12)

The choice of sign for q5 defines the Wrist Flip (normalized vs. flipped configuration).

### 4. Solution Selection and Configuration Ranking For any reachable target, the

analytical solver [6] generates a candidate set of up to 8 valid solutions (2 Base × 2 Elbow × 2 Wrist). Because analytical IK can be discontinuous—exhibiting "jerk" between branches—our solver utilizes a ranking and blending system to select the most stable solution:

- Configuration Hysteresis: A large "Branch Penalty" is applied to solutions that require a change in the robot’s fundamental mode (e.g., flipping the base or elbow). This ensures the robot stays within its current kinematic branch as long as it is reachable.
- Singularity-Aware Metric: Standard Euclidean distance is insufficient near singularities. Our metric downweights Joint 4 and 6 when near a wrist singularity (|sin(q5)| ≈ 0), as they become redundant. We also penalize deviations in the joint sum q4 + q6 to maintain consistent orientation.
- Dynamic Blend Zones: We implement a Lock-and-Blend strategy. Below a 3
| ◦
threshold, Joint 4 and 6 are hard-locked to their previous values. Between 3
| ◦ and
8

◦
, a linear blend factor smoothly transitions the solution from the previous state to the new analytical goal.
- Manipulability Ranking: Solutions are ranked using the Yoshikawa Manipulability Index (

q
det(JJT )) [4]. Configurations that are further away from geometric singularities (vertical arm, fully extended elbow) are prioritized.
- Velocity-Aware Penalty: The solver predicts the required joint velocity (q˙ = ∆q/∆t). Solutions that would require velocities exceeding the motor’s physical limits are heavily penalized to avoid physical tripping.

### 4.1.5 Role in the Control Loop

It is important to note that this Analytical Inverse Kinematics solver [6] is primarily used for simulation and global initialization. Because it is solved algebraically at a discrete pose, it is not inherently continuous. In the real-time control system, it serves as a Seeder for the Differential QP Controller (described in Section 4.3). The analytical solver provides a globally valid starting point, while the QP-based Jacobian solver ensures perfectly smooth, continuous joint trajectories during execution.

## 4.2 Differential IK via Quadratic Programming: A Constraint-Aware Framework

### Executive Summary

This report details our Differential QP Controller, which hybridizes analytical seeding with a numerical Quadratic Programming (QP) solver. By integrating Selectively Damped Least Squares (SDLS) and strict physical constraints via OSQP, the controller ensures robust, singularity-aware motion that overcomes the limitations of traditional numerical methods.

### 4.2.1 Introduction and Problem Formulation

The Kinematic Control Challenge in Modern Robotics

Inverse Kinematics (IK) constitutes the foundational layer of robotic manipulation, serving as the critical mathematical bridge between high-level task planning in Cartesian space and the low-level joint servo control required by actuators. The problem is formally defined as finding a joint configuration vector q ∈ R

n
that satisfies the non-linear mapping xdes = f(q), where xdes ∈ SE(3) represents the desired end-effector pose and f : R

n → SE(3) is the forward kinematics function.
While this formulation appears straightforward, practical implementation in industrial and collaborative environments introduces significant complexity. The function f(q) is highly non-linear, involving trigonometric compositions that result in non-convex solution spaces. Redundant manipulators possess an infinite set of solutions known as the selfmotion manifold. Conversely, non-redundant manipulators may have multiple discrete geometric solutions (branches), such as "elbow-up" or "elbow-down" configurations.

Limitations of Classical Numerical Solvers

Historically, the robotics community has relied on analytical and numerical solvers. Analytical solvers are fast and complete but specific to geometry and cannot easily incorporate inequality constraints. Numerical iterative methods offer generality by solving the problem at the velocity level:
x˙ = J(q)q˙ | (4.13)

where J(q) = ∂f/∂q ∈ R

m×n
is the manipulator Jacobian. However, these classical numerical approaches suffer from three critical pathologies:
- Local Minima Entrapment: Gradient-based solvers descend the error landscape from an initial guess. If initialized in the basin of attraction of a local minimum, the solver may converge to a state where the Cartesian error is non-zero, yet no local movement can reduce it.
- Singularity Instability: Near kinematic singularities (where rank(J) < m), the Jacobian becomes ill-conditioned. Pseudoinverse-based controllers command infinite joint velocities, leading to dangerous "jerk" or controller divergence.
- Constraint Violation: Pure kinematic inversion (q˙ = J

†x˙) is fundamentally unconstrained. It does not natively ensure that the resulting joint coordinates q remain within physical limits.

The Optimization Paradigm: Differential QP

Our controller addresses these limitations by reformulating the IK problem as a Constrained Quadratic Program (QP). By expressing the control objective as the minimization of a quadratic cost function subject to linear inequality constraints, the controller can optimally trade off tracking error against control effort while rigorously respecting physical boundaries.
This implementation utilizes the OSQP (Operator Splitting Quadratic Program) solver, a numerical engine tailored for sparse, convex problems. Crucially, the controller augments this optimization core with a Hybrid Architecture, utilizing an analytical solver [6] to seed the optimization. This combines the global topology awareness of analytical methods with the local constraint-handling capability of numerical optimization.

### 4.2.2 Mathematical Framework and Derivations

The efficacy of the controller rests on a rigorous mathematical formulation that translates physical robotic constraints into the language of convex optimization.

Differential Kinematics and Error Dynamics

The controller operates in a closed-loop real-time cycle (1 kHz). At each timestep t, the goal is to compute a joint velocity vector q˙ that minimizes the error between the current pose and the target pose.

Task-Space Error Formulation The translational error ep is the linear difference: ep = ptarget − pcurrent. The rotational error eo utilizes unit quaternions Q = [w, x, y, z]

T
To handle the double cover of SO(3), we explicitly check the inner product:
if (Qcurr · Qtarget < 0) =⇒ Qtarget ← −Qtarget | (4.14)

The orientation error is computed as: eo = 2 ln(Qtarget⊗Q⁻¹
curr). This prevents "unwinding" jumps and ensures rotation along the geodesic path.

Reference Velocity Generation The controller employs a Proportional (P) control law in task space:

vref = Kp

"
ep
eo
(4.15)

This linearizes the tracking dynamics, treating the robot as a first-order kinematic system.

### 4.2.3 Differential QP-Based Inverse Kinematics (OSQP Formulation)

### 1. Optimization problem being solved

At every control cycle, the solver computes a joint velocity command q˙ ∈ R

n
that best
tracks a desired Cartesian velocity while respecting joint limits. The problem is formulated as the following convex quadratic program:

min
q˙

1
2

||J(q)q˙ − vref ||²
W +

1
2

q˙

TΛq˙ | (4.16)
s.t. q˙ min ≤ q˙ ≤ q˙ max | (4.17)

Where:

- J ∈ R

6×n
is the geometric Jacobian.
- vref = Kpe is the desired Cartesian velocity.
- W is a task-space weighting matrix.
- Λ is an adaptive SDLS damping matrix.
- Constraints enforce joint velocity and joint-limit damping bounds.

### 2. Mapping to standard QP form (OSQP)

OSQP solves problems of the form:

min
x

1
2

x

TP x + q

T x | (4.18)
s.t. l ≤ Ax ≤ u | (4.19)

where x ∈ Rn
is the optimization variable and P ∈ S

n
+ a positive semidefinite matrix [5].

### 3. Objective function mapping

### 3.1 Quadratic term (Hessian) Expanding the least-squares objective:

||Jq˙ − vref ||²
W = q˙

T J

TWJq˙ − 2v

T
refWJq˙ + const | (4.20)

Thus, the Hessian is defined as: P = J

TWJ + Λ. In practice, a small ϵI is added for numerical positive definiteness.

- Code mapping:

P_dense = J . transpose () * W_diag * J + Lambda ;
P_dense += 1e -6 * Eigen :: MatrixXd :: Identity ( num_joints_ , num_joints_ ) ;

### 3.2 Linear term (gradient) The linear term of the QP is derived as: q = −J

TWvref .

- Code mapping:

q_grad_ = -J . transpose () * W_diag * v_ref ;

### 4. Constraints mapping

### 4.1 Constraint matrix Only box constraints are enforced: q˙ min ≤ q˙ ≤ q˙ max. This is

implemented via an identity constraint matrix A = In×n.

- Code mapping:

A_sparse_ . setIdentity () ;

### 4.2 Velocity Dampers for Joint Constraints An implementation detail is the use

of Velocity Dampers (also known as potential field limits or control barrier functions at the velocity level) to enforce position limits. This technique converts order-zero constraints (position) into order-one constraints (velocity), making them compatible with the differential QP formulation.
For a joint i with position limits [q

i

min, qi
max] and physical velocity limits [−v

i

max, vi
max],
the admissible velocity interval [ ˙q

i
lower, q˙

i
upper] is dynamically adjusted based on the proximity to the limits.
The upper velocity bound is defined as:

q˙

i
upper(t) = min
v

i

max, ξ q

i
| max − qi(t)
∆t

!
(4.21)

The lower velocity bound is defined as:

q˙

i
lower(t) = max

−v

i

max, ξ q

i
| min − qi(t)
∆t

!
(4.22)

where ξ is the velocity_damper_gain_ (typically ξ ∈ [0.1, 1.0]). This formulation acts as a "soft wall":

- Far from limit: The term ξ

dlimit
∆t

is large, so the bound is simply the physical motor limit vmax.

- Approaching limit: As the distance to the limit approaches zero, the allowable velocity linearly decreases, forcing the robot to decelerate smoothly.
- At limit: The velocity bound becomes zero (or negative), strictly preventing any motion that would violate the limit while permitting motion away from it.

These dynamic bounds are fed directly into the QP constraint vectors l and u (lef f and uef f in the code), ensuring that the optimization result is always "viable"—meaning a valid future trajectory exists.

Constraint Type | Physical Meaning | Mathematical Implementation
Box Constraint | Actuator Speed Limits | q˙ ∈ [−vmax, vmax]
Barrier Constraint | Joint Position Limits | q˙ ≤ ξ(qmax − q)/∆t
Optimization | Task Tracking | min ||Jq˙ − vref ||²
- Code mapping:

u_eff_ ( i ) = vel_upper ; l_eff_ ( i ) = - vel_lower ;

### 5. Selectively Damped Least Squares (SDLS)

To avoid over-damping well-conditioned directions, damping is applied per singular mode [1]:
Λ =

X

i

λ

2
i viv

T
i

(4.23)

Where the per-mode damping λi

follows a quadratic ramp:

λi =

λmax(1 − σi/σth)

2
if σi < σth
0 | otherwise

(4.24)

- Code mapping:

Lambda += ( lambda_i * lambda_i ) * V . col ( i ) * V . col ( i ) . transpose () ;

This preserves accuracy in non-singular directions while stabilizing the controller near rank-deficiencies.

### 6. Final solved QP (summary)

At each control step, OSQP solves the integrated objective:

min
q˙

1
2

q˙

T
(J

TWJ + Λ)q˙ − (J

TWvref )

T q˙ | (4.25)
s.t. q˙ min ≤ q˙ ≤ q˙ max | (4.26)

### 4.2.4 Hybrid Architecture: Topology and Global Awareness

Behind the optimization core, the controller implements a Motion Lookahead and Hysteresis mechanism to navigate the robot’s discrete configuration space.

Predictive Motion Lookahead

Instead of reacting only to the current error, the controller extrapolates the current trajectory to predict the robot’s pose in the near future:

plookahead = pcurrent +

epos
||epos|| · min(dlookahead, ||epos||) | (4.27)

The analytical IK is solved for this future pose. This effectively asks: "If we continue moving in this direction, will we need to flip the elbow or wrist?" If the detectBranch function identifies that the future pose requires a different configuration branch, the controller prepares to switch. This "proto-MPC" behavior allows the robot to anticipate kinematic bifurcations rather than stumbling into them blindly.

Hysteresis-Based Branch Switching

To prevent "chattering"—the rapid, unstable oscillation between configuration branches when near a workspace boundary—the controller implements a hysteresis filter. A switch is only permitted if the cost benefit of switching exceeds a predefined threshold:

Costswitch < Coststay − τhysteresis | (4.28)

The cost function computeBranchCost penalizes joint distance and manipulability loss:

Cost(q) = X(qi − qcurrent,i)

2 +

1
|sin(qwrist)| + ϵ

(4.29)

This logic ensures that the robot remains in its current valid configuration until the alternative becomes significantly better, mimicking the stability of biological motor control.

### 4.2.5 Implementation and Performance Evaluation

The system is implemented in C++ using the Eigen library and OSQP. We utilize Warm-Starting (initializing with the previous solution) to reduce solver iterations to ∼ 3 − 5 per cycle, enabling 1 kHz performance.
We evaluate performance through:
- Singularity Transit: Verifying stable velocity norms and graceful tracking degradation as σmin → 0.
- Elbow Flip Testing: Confirming 100% reachability in configuration-switching scenarios where standard local solvers fail.

## 4.3 Visualization and Control Interface

The robot is operated via a custom graphical user interface developed using the Qt/QML framework and C++. This application acts as the high-level controller, bridging the kinematic solvers with the real-time hardware telemetry.

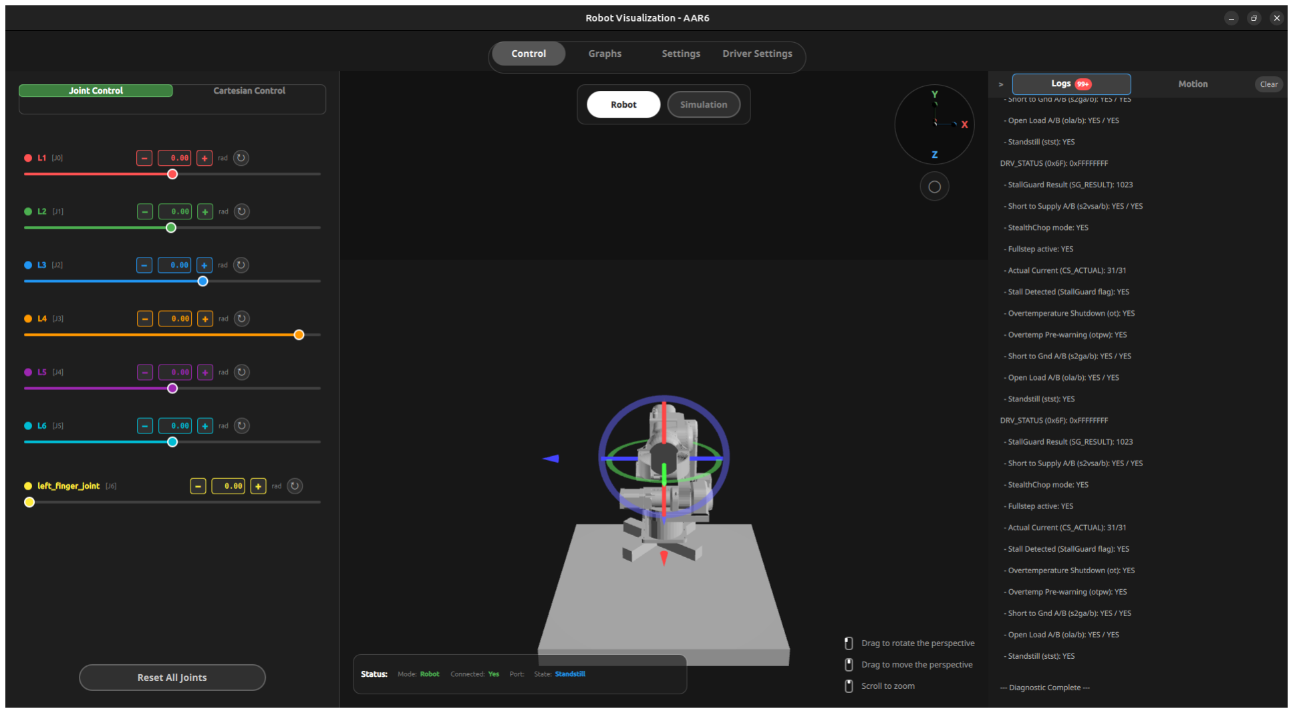
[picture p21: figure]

Figure 4.4: The Primary Control Interface showing the 3D robot model and control panels.

### 4.3.1 Connection and Initialization

The software includes an automated hardware detection system. Upon startup, it scans the available serial ports to identify the custom MCU. Once detected, the system prompts the user to connect:


Figure 4.5: The automated connection prompt and MCU detection status.

Upon successful connection, the software initiates a Homing Sequence. This ensures that the physical robot’s joint positions are synchronized with the internal kinematic model, establishing a verified zero-frame for all subsequent motions.

### 4.3.2 Control Modes and Input Methods

The interface utilizes a Model-View-Controller (MVC) architecture where the QML layer handles the interactive 3D rendering and 2D controls, while the C++ backend manages the thread-safe communication and IK computation.
Users can control the robot through several input modalities:
1. Cartesian Drag (3D Gizmo): An interactive 3D transform gizmo is attached to the end-effector in the 3D view. Users can drag this gizmo to move the robot in real-time. The software solves the Differential QP-IK at high frequency, streaming smooth trajectories to the MCU.

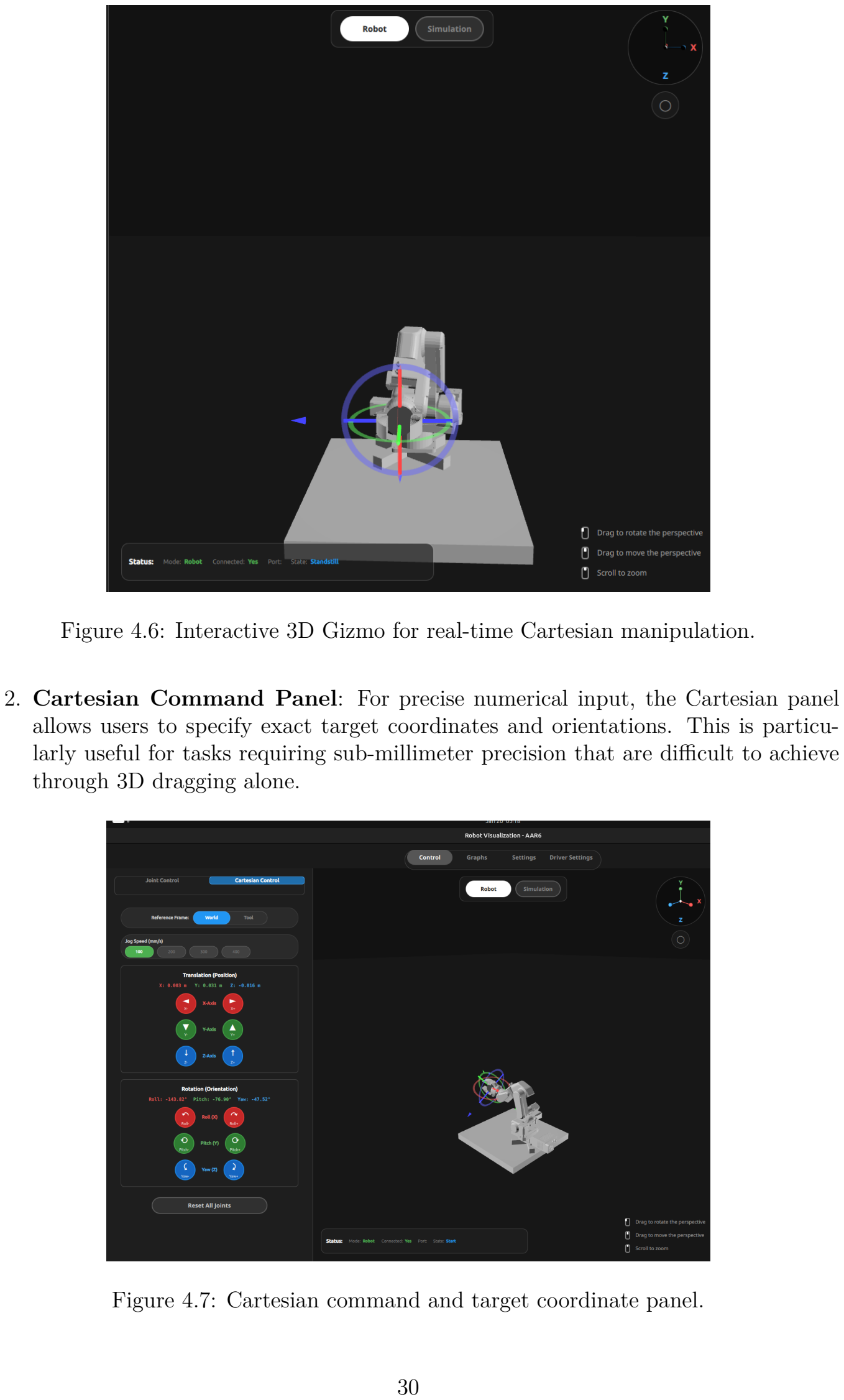
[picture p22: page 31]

Figure 4.6: Interactive 3D Gizmo for real-time Cartesian manipulation.

2. Cartesian Command Panel: For precise numerical input, the Cartesian panel allows users to specify exact target coordinates and orientations. This is particularly useful for tasks requiring sub-millimeter precision that are difficult to achieve through 3D dragging alone.

Figure 4.7: Cartesian command and target coordinate panel.

3. Joint-Space Sliders: Individual sliders permit direct manipulation of each joint angle (q1-q6). This is useful for manual configuration, diagnostic testing, and verification of individual actuator health.


Figure 4.8: Joint-space control interface (Sliders) and Cartesian command panel.

4. Motion Planning and Waypoints: The software features a dedicated Motion Controller and Panner. Users can add specific pose waypoints to a sequence and play them back. The system interpolates between these points using the internal S-Curve engine to ensure smooth transitions.

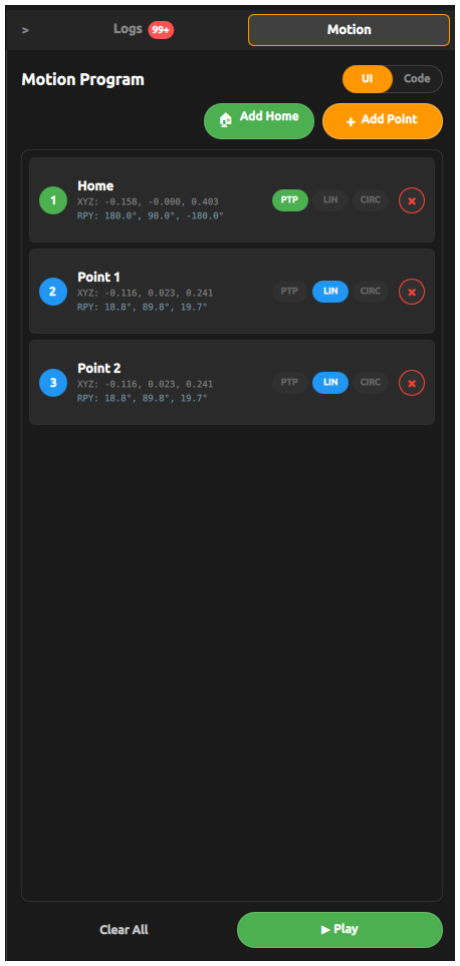
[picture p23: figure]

Figure 4.9: Motion waypoint sequence planner.

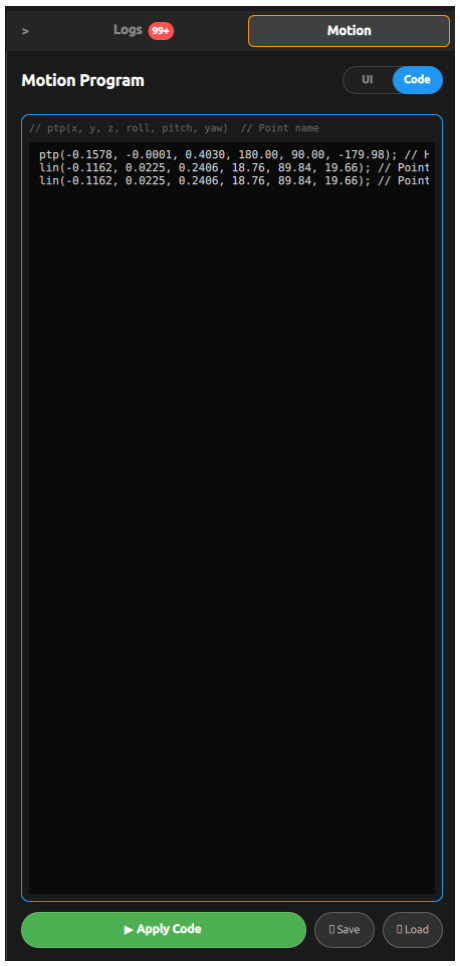
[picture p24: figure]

Figure 4.10: Integrated scripting and code interface.

5. Scripting Interface: For complex task automation, users can write code directly within the interface to execute logic-based motion sequences, integrating sensor feedback or timed events.

### 4.3.3 System Telemetry and Visualization

The 3D visualization is a mirror of the physical robot. As joint positions are streamed back from the MCU at 100 Hz, the 3D model is updated via the Forward Kinematics engine, providing the user with an accurate representation of the robot’s current state.


Figure 4.11: Real-time joint velocity and acceleration telemetry graphs.

## 4.4 Project Status: Limitations and Future Roadmap

The current implementation provides a high-fidelity 6-DOF control system; however, technical constraints across hardware, control logic, and software frameworks define the roadmap for future development.

### 4.4.1 Hardware and Connectivity

- Actuator Driver Status (J3): The system is currently missing two primary drivers. A temporary "jerry-rigged" driver is currently in use for Joint 3 (J3); however, it is prone to thermal shutdowns due to temperature regulation issues and must be replaced. This failure mode was precipitated by high Back-EMF from J3, which destroyed two previous drivers. A high-quality, high-EMF-rated driver is required for stable long-term operation (TMC5160 Product Page). (https://biqu.equipment/products/bigtreetech-tmc5160-v1-0-driver-spi-mode-silent-high-precision-stepstick-stepper-motor-driver-with-heatsink-for-skr-v1-3-gen-v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)
- End-Effector (Gripper) Status: The gripper is currently disconnected from the control loop. This is due to a combination of time constraints and the aforementioned driver failures, leaving insufficient functional drivers for complete integration.
- Payload and Mass Distribution: The NEMA-style stepper motor used for the gripper adds approximately 300 g of dead weight at the end of the arm. This significantly reduces the effective payload capacity and increases the inertial load during high-acceleration maneuvers.
- Position Encoders (AS5600): The AS5600 magnetic encoders are currently not connected to the control loop. Once integrated, these will enable Admittance

Control and adjustable arm stiffness. This hardware capability will allow for "leadthrough" programming, where the user can teach the robot new paths simply by physically moving the arm.
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

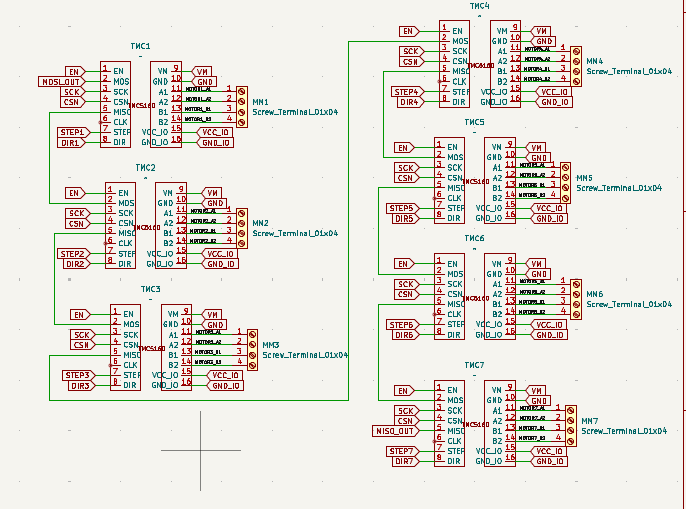
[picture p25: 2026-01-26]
documentation/images/motor schematics.png

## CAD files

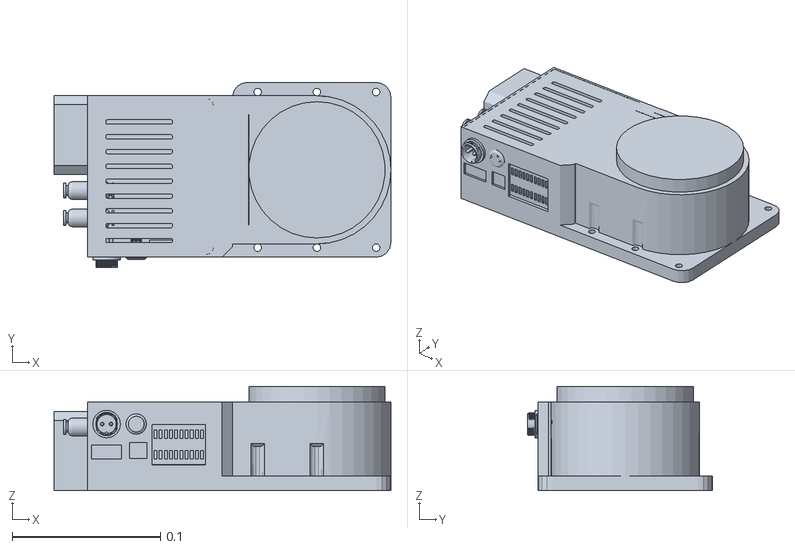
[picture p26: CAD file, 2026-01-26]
Robot_controller/resources/aar6/meshes/base_link.STL
0.227 x 0.125 x 0.0705

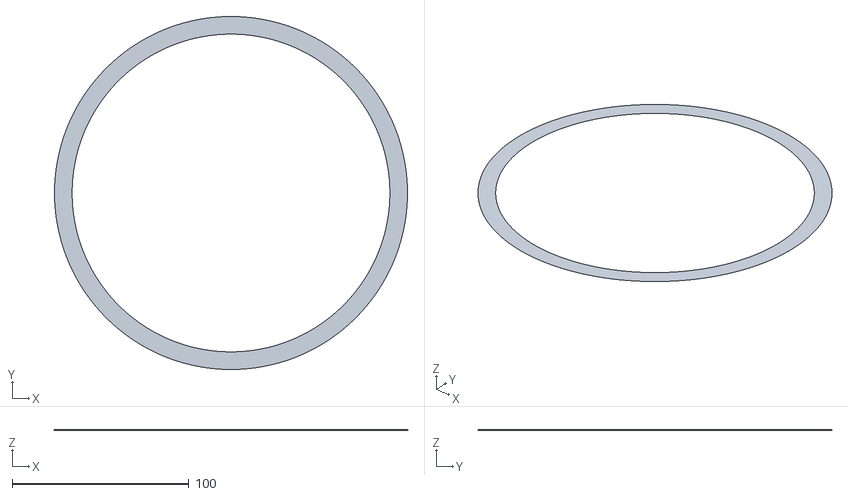
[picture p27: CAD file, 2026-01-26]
Robot_controller/visualization/resources/3d/falt_touros.stl
200.0 x 200.0 x 0.1

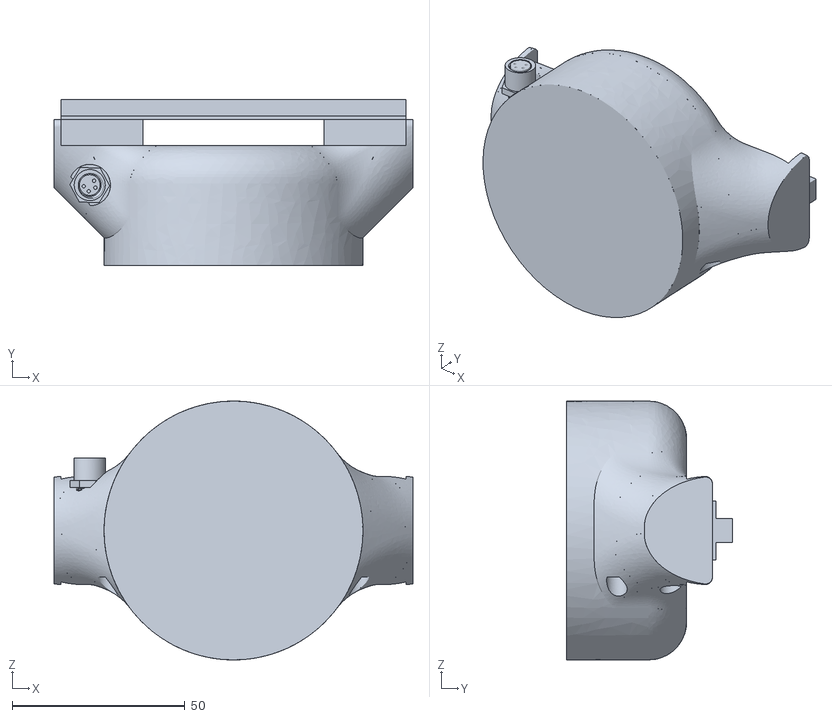
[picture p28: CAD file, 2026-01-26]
Robot_controller/resources/aar6/meshes/Gripper_Body.STL
104.0 x 48.0 x 75.0

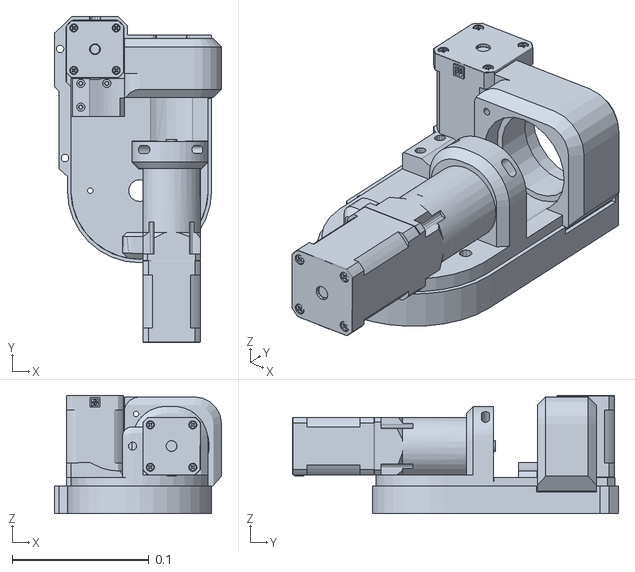
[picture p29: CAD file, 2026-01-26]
Robot_controller/resources/aar6/meshes/L1.STL
0.122 x 0.238 x 0.0863

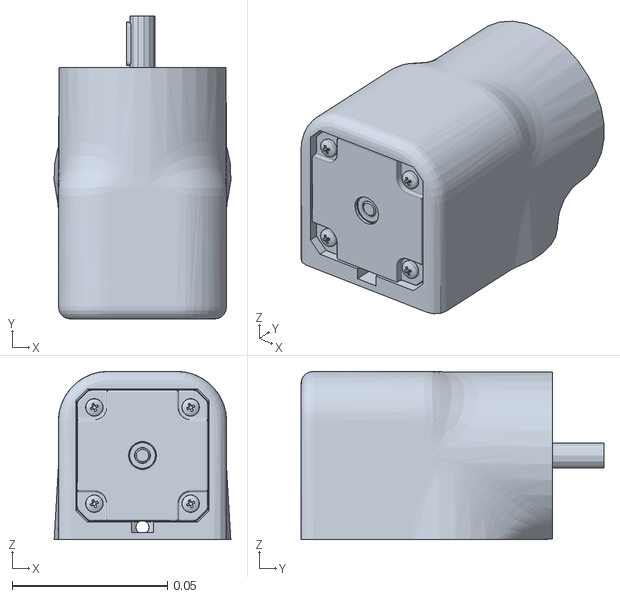
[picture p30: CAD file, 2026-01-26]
Robot_controller/resources/aar6/meshes/L5.STL
0.0569 x 0.0975 x 0.0541

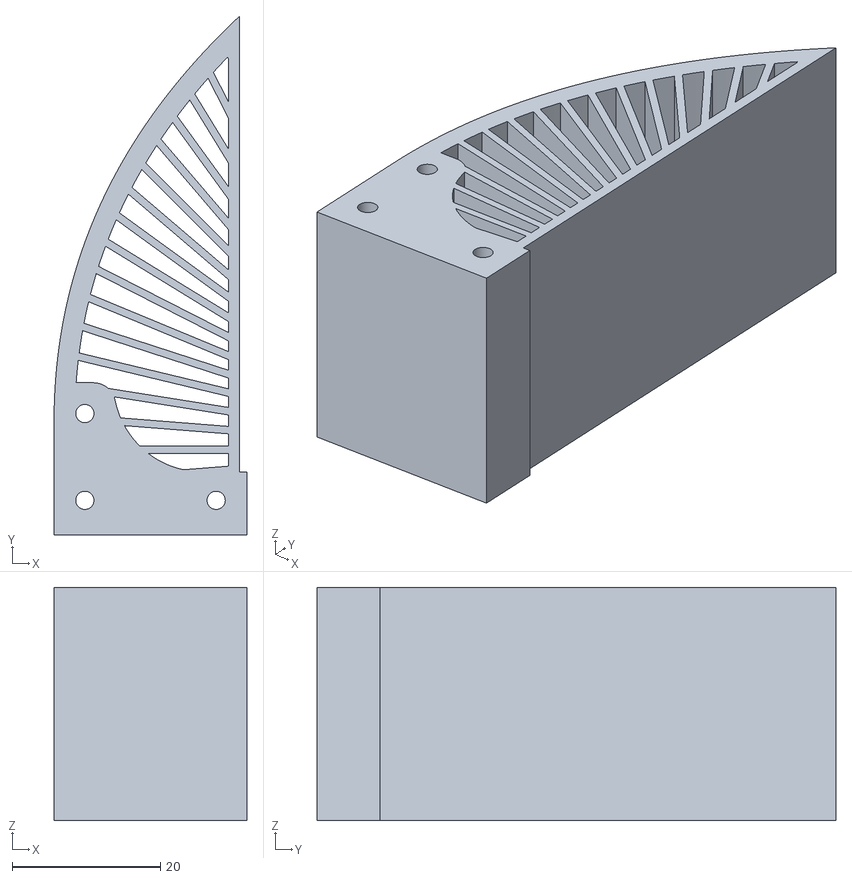
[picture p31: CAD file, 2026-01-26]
Robot_controller/resources/aar6/meshes/gripper_finger.STL
26.0 x 69.9 x 31.4

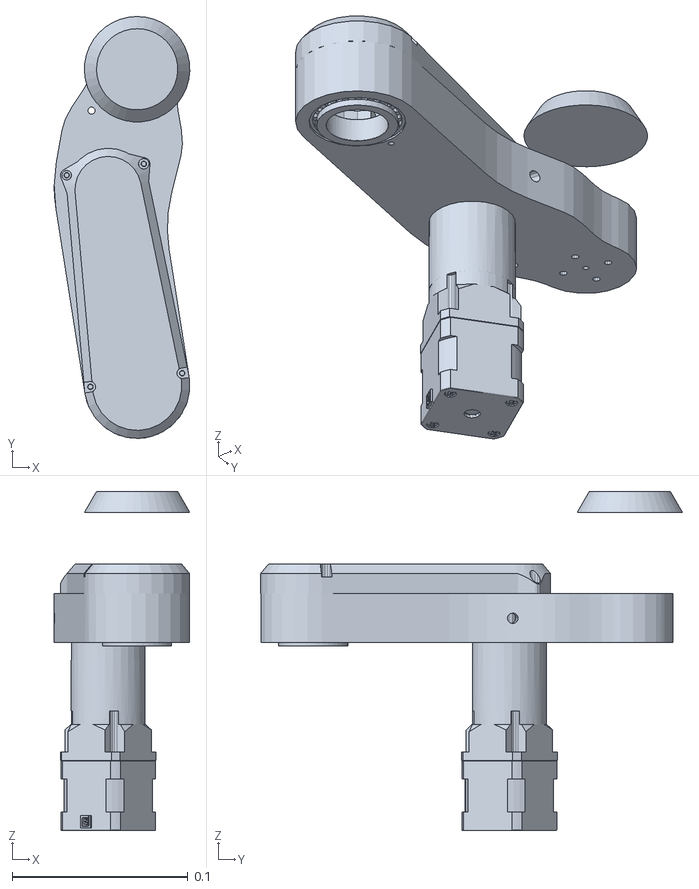
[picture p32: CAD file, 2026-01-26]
Robot_controller/resources/aar6/meshes/L2.STL
0.0771 x 0.24 x 0.193

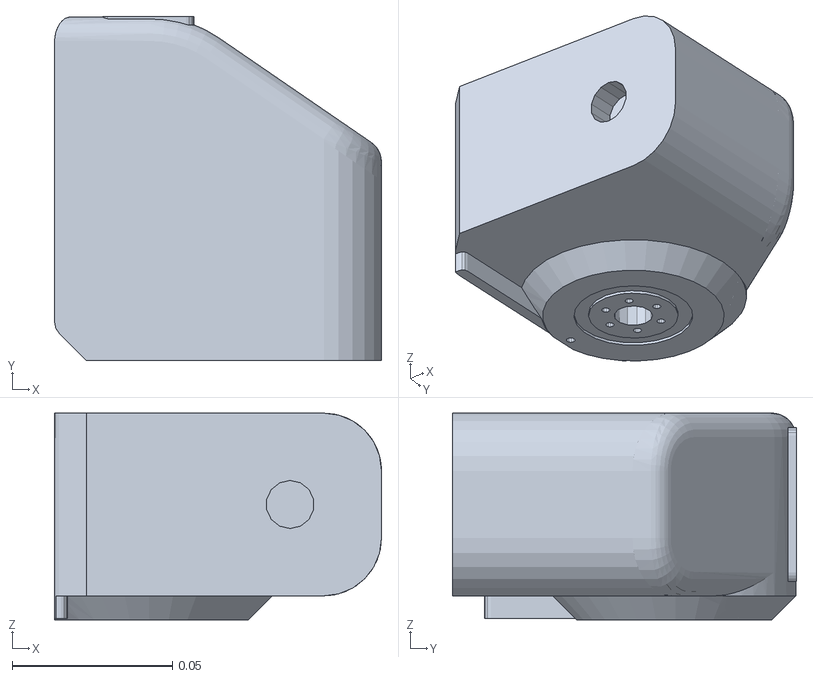
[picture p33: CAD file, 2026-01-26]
Robot_controller/resources/aar6/meshes/L3.STL
0.102 x 0.107 x 0.0645

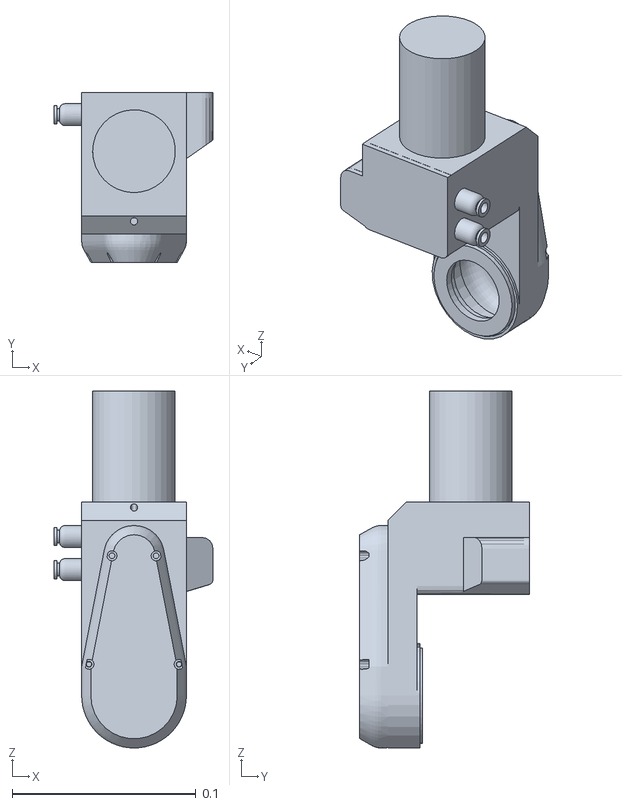
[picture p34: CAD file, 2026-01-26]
Robot_controller/resources/aar6/meshes/L4.STL
0.0864 x 0.0923 x 0.194

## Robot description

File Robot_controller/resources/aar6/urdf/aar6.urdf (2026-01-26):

<?xml version="1.0" encoding="utf-8"?>
<robot name="aar6">

  <link name="world"/>
  
  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
  <link name="wooden_base">
    <inertial>
      <origin xyz="0 0 0" rpy="0 0 0"/>
      <mass value="5.0"/>
      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
    </inertial>
    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
  </link>
  
  <joint name="world_to_wooden_base" type="fixed">
    <parent link="world"/>
    <child link="wooden_base"/>
    <origin xyz="0.0 0.0 0.0" rpy="0 0 0"/>
  </joint>
  
  <joint name="base_joint" type="fixed">
    <parent link="wooden_base"/>
    <child link="base_link"/>
    <origin rpy="0 0 3.142" xyz="0.145 0.0 0.069"/>
  </joint>


  <link name="base_link">
    <inertial>
      <origin xyz="-0.0274562034602567 -0.00137265400595656 0.031237920982338" rpy="0 0 0" />
      <mass value="0.812661291810144" />
      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
    </inertial>
    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
  </link>
  <link name="L1">
    <inertial>
      <origin xyz="0.00524529891406311 0.0289722820784871 0.992791429452917" rpy="0 0 0" />
      <mass value="0.644800830530233" />
      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
    </inertial>
    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
  </link>
  <joint name="L1" type="revolute">
    <origin xyz="0 0 0" rpy="0 0 0" />
    <parent link="base_link" />
    <child link="L1" />
    <axis xyz="0 0 1" />
    <limit lower="-3.142" upper="3.142" effort="300" velocity="15" />
  </joint>
  <link name="L2">
    <inertial>
      <origin xyz="-0.0094181617193695 -0.0783879603613605 0.0369429741417731" rpy="0 0 0" />
      <mass value="0.512334779399788" />
      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
    </inertial>
    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
  </link>
  <joint name="L2" type="revolute">
    <origin xyz="0.0234207210610375 0 0.1105" rpy="-1.5707963267949 0 0" />
    <parent link="L1" />
    <child link="L2" />
    <axis xyz="0 0 1" />
    <limit lower="-0.98" upper="1" effort="300" velocity="15" />
  </joint>
  <link name="L3">
    <inertial>
      <origin xyz="0.0155509885239593 -0.0191127686426613 -0.00153322577917236" rpy="0 0 0" />
      <mass value="0.550970997806044" />
      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
    </inertial>
    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
  </link>
  <joint name="L3" type="revolute">
    <origin xyz="0 -0.18 0" rpy="3.1416 0 -1.5708" />
    <parent link="L2" />
    <child link="L3" />
    <axis xyz="0 0 -1" />
    <limit lower="-2" upper="1.3" effort="300" velocity="15" />
  </joint>
  <link name="L4">
    <inertial>
      <origin xyz="0.000947028430634433 -0.008978947112462 -0.0924798659827059" rpy="0 0 0" />
      <mass value="0.39346362633915" />
      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
    </inertial>
    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
  </link>
  <joint name="L4" type="revolute">
    <origin xyz="0.0435 0 0" rpy="1.5707963267949 0 3.14159265358979" />
    <parent link="L3" />
    <child link="L4" />
    <axis xyz="0 0 -1" />
    <limit lower="-4.9" upper="0.3" effort="300" velocity="15" />
  </joint>
  <link name="L5">
    <inertial>
      <origin xyz="6.7162171684676E-06 -0.00621420980825221 -0.000960871025916146" rpy="0 0 0" />
      <mass value="0.185171777001718" />
      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
    </inertial>
    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
  </link>
  <joint name="L5" type="revolute">
    <origin xyz="0 0 -0.17635" rpy="-1.5708 0 0" />
    <parent link="L4" />
    <child link="L5" />
    <axis xyz="0 0 -1" />
    <limit lower="-2.1" upper="2.1" effort="300" velocity="15" />
  </joint>
  <link name="L6">
    <inertial>
      <origin xyz="0.00632955087228015 -0.000453856352095022 -0.0554441567386594" rpy="0 0 0" />
      <mass value="0.0703261410665101" />
      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
    </inertial>
    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
  </link>
  <joint name="L6" type="continuous">
     <origin xyz="0 0.051 0" rpy="1.5708 0 0" />
    <parent link="L5" />
    <child link="L6" />
    <axis xyz="0 0 -1" />
    <limit lower="-3.1" upper="3.1" effort="300" velocity="15" />
  </joint>
  <link name="ee_link">
    <inertial>
      <origin xyz="0 0 0" rpy="0 0 0" />
      <mass value="0.0703261410665101" />
      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
    </inertial>

  </link>
  <joint name="ee_link" type="fixed">
    <origin xyz="0 0 -0.052" rpy="0 0 0"/>
    <parent link="L6" />
    <child link="ee_link" />
    <axis xyz="0 0 0" />
    
  </joint>


<link name="left_finger">
  <inertial>
    <origin xyz="0 0 0" rpy="0 0 0"/>
 <mass value="0.025"/>
    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
  </inertial>
  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
</link>

  <joint name="left_finger_joint" type="prismatic">
    <parent link="L6"/>
    <child link="left_finger"/>
    <origin xyz="-0.00 0.038 -0.053" rpy="-1.5708 0 0"/>
      <axis xyz="0 0 -1"/>
    <limit lower="0.0" upper="0.025" effort="10" velocity="0.05"/>
      <dynamics damping="50.0" friction="0.0"/>

  </joint>

 <link name="right_finger">
  <inertial>
    <origin xyz="0 0 0" rpy="0 0 0"/>
     <mass value="0.025"/>
    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
  </inertial>
  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
</link>

  <joint name="right_finger_joint" type="prismatic">
    <parent link="L6"/>
    <child link="right_finger"/>
    <origin xyz="0.0 -0.04 -0.053" rpy="-1.5708 0 0"/>
    <axis xyz="0 0 1"/>
    <limit lower="0.0" upper="0.025" effort="10" velocity="0.05"/>
    <mimic joint="left_finger_joint" multiplier="1.0" offset="0"/>
      <dynamics damping="50.0" friction="0.0"/>

  </joint>

  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

<ros2_control name="AAR6_System" type="system">
    <hardware>
      <plugin>mock_components/GenericSystem</plugin>
    </hardware>

    <joint name="L1">
      <command_interface name="velocity"/>
      <state_interface name="position">
        <param name="initial_value">0.0</param>
      </state_interface>
      <state_interface name="velocity"/>
    </joint>

    <joint name="L2">
      <command_interface name="velocity"/>
      <state_interface name="position">
        <param name="initial_value">0.0</param>
      </state_interface>
      <state_interface name="velocity"/>
    </joint>

    <joint name="L3">
      <command_interface name="velocity"/>
      <state_interface name="position">
        <param name="initial_value">0.0</param>
      </state_interface>
      <state_interface name="velocity"/>
    </joint>

    <joint name="L4">
      <command_interface name="velocity"/>
      <state_interface name="position">
        <param name="initial_value">0.0</param>
      </state_interface>
      <state_interface name="velocity"/>
    </joint>

    <joint name="L5">
      <command_interface name="velocity"/>
      <state_interface name="position">
        <param name="initial_value">0.0</param>
      </state_interface>
      <state_interface name="velocity"/>
    </joint>

    <joint name="L6">
      <command_interface name="velocity"/>
      <state_interface name="position">
        <param name="initial_value">0.0</param>
      </state_interface>
      <state_interface name="velocity"/>
    </joint>
  </ros2_control>

</robot>

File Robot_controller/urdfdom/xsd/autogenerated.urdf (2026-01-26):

<?xml version="1.0" encoding="utf-8"?>
<robot name="name1" version="1.0" xmlns="http://www.ros.org">
  <joint name="name1" type="type1">
    <mimic joint="joint1" multiplier="1" offset="0" />
    <safety_controller soft_lower_limit="0" soft_upper_limit="0" k_position="0" k_velocity="1" />
    <limit lower="0" upper="0" effort="0" velocity="0" />
    <dynamics damping="0" friction="0" />
    <calibration reference_position="1" rising="1" falling="1" />
    <axis xyz="1 0 0" />
    <child link="link1" />
    <parent link="link1" />
    <origin xyz="0 0 0" rpy="0 0 0" />
  </joint>
  <joint name="name2" type="type2">
    <mimic joint="joint2" multiplier="1" offset="1" />
    <safety_controller soft_lower_limit="1" soft_upper_limit="1" k_position="1" k_velocity="-1.7976931348623157E+308" />
    <limit lower="1" upper="1" effort="1" velocity="1" />
    <dynamics damping="1" friction="1" />
    <calibration reference_position="-1.7976931348623157E+308" rising="-1.7976931348623157E+308" falling="-1.7976931348623157E+308" />
    <axis xyz="xyz1" />
    <child link="link2" />
    <parent link="link2" />
    <origin xyz="xyz1" rpy="rpy1" />
  </joint>
  <joint name="name3" type="type3">
    <mimic joint="joint3" multiplier="-1.7976931348623157E+308" offset="-1.7976931348623157E+308" />
    <safety_controller soft_lower_limit="-1.7976931348623157E+308" soft_upper_limit="-1.7976931348623157E+308" k_position="-1.7976931348623157E+308" k_velocity="1.7976931348623157E+308" />
    <limit lower="-1.7976931348623157E+308" upper="-1.7976931348623157E+308" effort="-1.7976931348623157E+308" velocity="-1.7976931348623157E+308" />
    <dynamics damping="-1.7976931348623157E+308" friction="-1.7976931348623157E+308" />
    <calibration reference_position="1.7976931348623157E+308" rising="1.7976931348623157E+308" falling="1.7976931348623157E+308" />
    <axis xyz="xyz2" />
    <child link="link3" />
    <parent link="link3" />
    <origin xyz="xyz2" rpy="rpy2" />
  </joint>
  <link name="name1" type="type1">
    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
    <inertial>
      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
      <mass value="0" />
      <origin xyz="0 0 0" rpy="0 0 0" />
    </inertial>
  </link>
  <link name="name2" type="type2">
    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
    <inertial>
      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
      <mass value="1" />
      <origin xyz="xyz1" rpy="rpy1" />
    </inertial>
  </link>
  <link name="name3" type="type3">
    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
    <inertial>
      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
      <mass value="-1.7976931348623157E+308" />
      <origin xyz="xyz2" rpy="rpy2" />
    </inertial>
  </link>
  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
  <joint name="name4" type="type4">
    <mimic joint="joint4" multiplier="1.7976931348623157E+308" offset="1.7976931348623157E+308" />
    <safety_controller soft_lower_limit="1.7976931348623157E+308" soft_upper_limit="1.7976931348623157E+308" k_position="1.7976931348623157E+308" k_velocity="-0.10000002384185791" />
    <limit lower="1.7976931348623157E+308" upper="1.7976931348623157E+308" effort="1.7976931348623157E+308" velocity="1.7976931348623157E+308" />
    <dynamics damping="1.7976931348623157E+308" friction="1.7976931348623157E+308" />
    <calibration reference_position="-0.10000002384185791" rising="-0.10000002384185791" falling="-0.10000002384185791" />
    <axis xyz="xyz3" />
    <child link="link4" />
    <parent link="link4" />
    <origin xyz="xyz3" rpy="rpy3" />
  </joint>
  <joint name="name5" type="type5">
    <mimic joint="joint5" multiplier="-0.10000002384185791" offset="-0.10000002384185791" />
    <safety_controller soft_lower_limit="-0.10000002384185791" soft_upper_limit="-0.10000002384185791" k_position="-0.10000002384185791" k_velocity="2.1000000238418579" />
    <limit lower="-0.10000002384185791" upper="-0.10000002384185791" effort="-0.10000002384185791" velocity="-0.10000002384185791" />
    <dynamics damping="-0.10000002384185791" friction="-0.10000002384185791" />
    <calibration reference_position="2.1000000238418579" rising="2.1000000238418579" falling="2.1000000238418579" />
    <axis xyz="xyz4" />
    <child link="link5" />
    <parent link="link5" />
    <origin xyz="xyz4" rpy="rpy4" />
  </joint>
  <joint name="name6" type="type6">
    <mimic joint="joint6" multiplier="2.1000000238418579" offset="2.1000000238418579" />
    <safety_controller soft_lower_limit="2.1000000238418579" soft_upper_limit="2.1000000238418579" k_position="2.1000000238418579" k_velocity="-1.7976931348623157E+308" />
    <limit lower="2.1000000238418579" upper="2.1000000238418579" effort="2.1000000238418579" velocity="2.1000000238418579" />
    <dynamics damping="2.1000000238418579" friction="2.1000000238418579" />
    <calibration reference_position="-1.7976931348623157E+308" rising="-1.7976931348623157E+308" falling="-1.7976931348623157E+308" />
    <axis xyz="xyz5" />
    <child link="link6" />
    <parent link="link6" />
    <origin xyz="xyz5" rpy="rpy5" />
  </joint>
  <link name="name4" type="type4">
    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
    <inertial>
      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
      <mass value="1.7976931348623157E+308" />
      <origin xyz="xyz3" rpy="rpy3" />
    </inertial>
  </link>
  <link name="name5" type="type5">
    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
    <inertial>
      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
      <mass value="-0.10000002384185791" />
      <origin xyz="xyz4" rpy="rpy4" />
    </inertial>
  </link>
  <link name="name6" type="type6">
    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
    <inertial>
      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
      <mass value="2.1000000238418579" />
      <origin xyz="xyz5" rpy="rpy5" />
    </inertial>
  </link>
  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
  <joint name="name7" type="type7">
    <mimic joint="joint7" multiplier="-1.7976931348623157E+308" offset="-1.7976931348623157E+308" />
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

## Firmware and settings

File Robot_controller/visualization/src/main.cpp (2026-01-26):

#include "AppState.h"
#include "MotionController.h"
#include "MotionPlannerModel.h"
#include "RobotManager.h"
#include "RobotNode.h"
#include <QGuiApplication>
#include <QQmlApplicationEngine>
#include <QQmlContext>
#include <QQuickWindow>
#include <iostream>

int main(int argc, char *argv[]) {
  QGuiApplication app(argc, argv);

  // Print which graphics API Qt will use
  auto api = QQuickWindow::graphicsApi();
  std::cout << "Qt Graphics API: ";
  switch (api) {
  case QSGRendererInterface::OpenGL:
    std::cout << "OpenGL (GPU)";
    break;
  case QSGRendererInterface::Vulkan:
    std::cout << "Vulkan (GPU)";
    break;
  case QSGRendererInterface::Direct3D11:
    std::cout << "Direct3D 11 (GPU)";
    break;
  case QSGRendererInterface::Metal:
    std::cout << "Metal (GPU)";
    break;
  case QSGRendererInterface::Software:
    std::cout << "Software (CPU - slow!)";
    break;
  default:
    std::cout << "Unknown (" << static_cast<int>(api) << ")";
    break;
  }
  std::cout << std::endl;

  // Register QML types
  qmlRegisterType<RobotNode>("RobotVisualization", 1, 0, "RobotNode");
  qmlRegisterType<WaypointListModel>("RobotVisualization", 1, 0,
                                     "WaypointListModel");
  qmlRegisterType<AppState>("RobotVisualization", 1, 0, "AppState");
  qmlRegisterType<MotionController>("RobotVisualization", 1, 0,
                                    "MotionController");

  QQmlApplicationEngine engine;

  // Create RobotManager instance
  RobotManager robotManager;
  engine.rootContext()->setContextProperty("robotManager", &robotManager);

  // Pass command line args to QML
  QStringList args;
  for (int i = 0; i < argc; ++i)
    args << argv[i];
  engine.rootContext()->setContextProperty("appArgs", args);

  // Load main.qml from the embedded resource system
  const QUrl url("qrc:/Visualization/qml/main.qml");

  QObject::connect(
      &engine, &QQmlApplicationEngine::objectCreated, &app,
      [url](QObject *obj, const QUrl &objUrl) {
        if (!obj && url == objUrl) {
          std::cerr << "Failed to load QML component from: "
                    << url.toString().toStdString() << std::endl;
          QCoreApplication::exit(-1);
        }
      },
      Qt::QueuedConnection);

  engine.load(url);

  return app.exec();
}

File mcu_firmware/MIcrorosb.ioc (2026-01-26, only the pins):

Mcu.UserName=STM32F446RETx
PA0-WKUP.GPIO_Label=STEP3
PA0-WKUP.Signal=S_TIM5_CH1
PA10.GPIO_Label=DIR6
PA10.Signal=GPIO_Output
PA11.GPIO_Label=EN
PA11.Signal=GPIO_Output
PA12.GPIO_Label=DIR7
PA12.Signal=GPIO_Output
PA2.Signal=USART2_TX
PA3.Signal=USART2_RX
PA4.GPIO_Label=CS
PA4.Signal=GPIO_Output
PA5.Signal=SPI1_SCK
PA6.Signal=SPI1_MISO
PA7.Signal=SPI1_MOSI
PA8.Signal=I2C3_SCL
PB10.GPIO_Label=LIMIT2
PB10.Signal=GPXTI10
PB14.GPIO_Label=STEP7
PB14.Signal=S_TIM12_CH1
PB5.GPIO_Label=LIMIT3
PB5.Signal=GPXTI5
PB6.GPIO_Label=STEP2
PB6.Signal=S_TIM4_CH1
PB7.GPIO_Label=LIMIT4
PB7.Signal=GPXTI7
PB8.GPIO_Label=STEP5
PB8.Signal=S_TIM10_CH1
PB9.GPIO_Label=STEP6
PB9.Signal=S_TIM11_CH1
PC0.GPIO_Label=LIMIT6
PC0.Signal=GPXTI0
PC1.GPIO_Label=DIR1
PC1.Signal=GPIO_Output
PC10.GPIO_Label=DIR5
PC10.Signal=GPIO_Output
PC11.GPIO_Label=DIR4
PC11.Signal=GPIO_Output
PC12.GPIO_Label=DIR3
PC12.Signal=GPIO_Output
PC3.GPIO_Label=LIMIT1
PC3.Signal=GPXTI3
PC6.GPIO_Label=STEP4
PC6.Signal=S_TIM8_CH1
PC7.GPIO_Label=STEP1
PC7.Signal=S_TIM3_CH2
PC8.GPIO_Label=LIMIT5
PC8.Signal=GPXTI8
PC9.Signal=I2C3_SDA
PD2.GPIO_Label=DIR2
PD2.Signal=GPIO_Output
PH0-OSC_IN.Signal=RCC_OSC_IN
PH1-OSC_OUT.Signal=RCC_OSC_OUT

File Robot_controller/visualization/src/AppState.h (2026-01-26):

#ifndef APPSTATE_H
#define APPSTATE_H

#include <QObject>
#include <QVariantList>
#include <QVariantMap>
#include <QVector3D>
#include <QtQml/qqmlregistration.h>

/**
 * AppState - Consolidated application state for the robot visualization
 *
 * This QObject centralizes scattered window properties to simplify
 * passing state to QML components via a single appState property.
 */
class AppState : public QObject {
  Q_OBJECT
  QML_ELEMENT

  // ========================================
  // MODE CONTROL
  // ========================================
  Q_PROPERTY(bool isSimulationMode READ isSimulationMode WRITE
                 setIsSimulationMode NOTIFY isSimulationModeChanged)
  Q_PROPERTY(
      bool showGizmo READ showGizmo WRITE setShowGizmo NOTIFY showGizmoChanged)

  // ========================================
  // IK CONTROL
  // ========================================
  Q_PROPERTY(
      bool ikEnabled READ ikEnabled WRITE setIkEnabled NOTIFY ikEnabledChanged)
  Q_PROPERTY(
      bool ikSolving READ ikSolving WRITE setIkSolving NOTIFY ikSolvingChanged)
  Q_PROPERTY(QString ikStatusText READ ikStatusText WRITE setIkStatusText NOTIFY
                 ikStatusTextChanged)
  Q_PROPERTY(QVector3D lastValidGizmoPosition READ lastValidGizmoPosition WRITE
                 setLastValidGizmoPosition NOTIFY lastValidGizmoPositionChanged)
  Q_PROPERTY(QVariantList ikJointNames READ ikJointNames CONSTANT)

  // ========================================
  // CARTESIAN CONTROL
  // ========================================
  Q_PROPERTY(QVariantList cartesianStepSizes READ cartesianStepSizes CONSTANT)
  Q_PROPERTY(int cartesianStepIndex READ cartesianStepIndex WRITE
                 setCartesianStepIndex NOTIFY cartesianStepIndexChanged)
  Q_PROPERTY(double cartesianStepSize READ cartesianStepSize NOTIFY
                 cartesianStepIndexChanged)

  Q_PROPERTY(QVariantList rotationStepSizes READ rotationStepSizes CONSTANT)
  Q_PROPERTY(int rotationStepIndex READ rotationStepIndex WRITE
                 setRotationStepIndex NOTIFY rotationStepIndexChanged)
  Q_PROPERTY(double rotationStepSize READ rotationStepSize NOTIFY
                 rotationStepIndexChanged)

  Q_PROPERTY(bool useLocalFrame READ useLocalFrame WRITE setUseLocalFrame NOTIFY
                 useLocalFrameChanged)

  // ========================================
  // JOINT STATE
  // ========================================
  Q_PROPERTY(QVariantMap jointAngles READ jointAngles WRITE setJointAngles
                 NOTIFY jointAnglesChanged)
  Q_PROPERTY(QVariantList currentJointPositions READ currentJointPositions WRITE
                 setCurrentJointPositions NOTIFY currentJointPositionsChanged)
  Q_PROPERTY(
      QVariantList simulationJointPositions READ simulationJointPositions WRITE
          setSimulationJointPositions NOTIFY simulationJointPositionsChanged)
  Q_PROPERTY(QVariantList jointColors READ jointColors CONSTANT)

  // ========================================
  // GRAPH STATE
  // ========================================
  Q_PROPERTY(int maxDataPoints READ maxDataPoints CONSTANT)
  Q_PROPERTY(int dataUpdateTrigger READ dataUpdateTrigger NOTIFY
                 dataUpdateTriggerChanged)
  Q_PROPERTY(double graphTimeZoom READ graphTimeZoom WRITE setGraphTimeZoom
                 NOTIFY graphTimeZoomChanged)
  Q_PROPERTY(double graphTimeOffset READ graphTimeOffset WRITE
                 setGraphTimeOffset NOTIFY graphTimeOffsetChanged)
  Q_PROPERTY(QVariantList selectedJoints READ selectedJoints WRITE
                 setSelectedJoints NOTIFY selectedJointsChanged)
  Q_PROPERTY(bool useRadians READ useRadians WRITE setUseRadians NOTIFY
                 useRadiansChanged)

  // ========================================
  // COLLISION STATE
  // ========================================
  Q_PROPERTY(QVariantList collidingPairs READ collidingPairs WRITE
                 setCollidingPairs NOTIFY collidingPairsChanged)
  Q_PROPERTY(QVariantMap collidingLinks READ collidingLinks WRITE
                 setCollidingLinks NOTIFY collidingLinksChanged)
  Q_PROPERTY(QVariantList collisionColors READ collisionColors CONSTANT)

  // ========================================
  // CAMERA STATE
  // ========================================
  Q_PROPERTY(double cameraDistance READ cameraDistance WRITE setCameraDistance
                 NOTIFY cameraDistanceChanged)
  Q_PROPERTY(
      double panSpeed READ panSpeed WRITE setPanSpeed NOTIFY panSpeedChanged)
  Q_PROPERTY(double orbitSpeed READ orbitSpeed WRITE setOrbitSpeed NOTIFY
                 orbitSpeedChanged)
  Q_PROPERTY(double zoomSpeed READ zoomSpeed WRITE setZoomSpeed NOTIFY
                 zoomSpeedChanged)

  // ========================================
  // SETTINGS
  // ========================================
  Q_PROPERTY(QString selectedDevice READ selectedDevice WRITE setSelectedDevice
                 NOTIFY selectedDeviceChanged)
  Q_PROPERTY(int selectedBaudrate READ selectedBaudrate WRITE
                 setSelectedBaudrate NOTIFY selectedBaudrateChanged)
  Q_PROPERTY(QVariantList availableBaudrates READ availableBaudrates CONSTANT)
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

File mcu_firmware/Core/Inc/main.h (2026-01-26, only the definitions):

#define LIMIT6_Pin GPIO_PIN_0
#define LIMIT6_GPIO_Port GPIOC
#define LIMIT6_EXTI_IRQn EXTI0_IRQn
#define DIR1_Pin GPIO_PIN_1
#define DIR1_GPIO_Port GPIOC
#define LIMIT1_Pin GPIO_PIN_3
#define LIMIT1_GPIO_Port GPIOC
#define LIMIT1_EXTI_IRQn EXTI3_IRQn
#define STEP3_Pin GPIO_PIN_0
#define STEP3_GPIO_Port GPIOA
#define CS_Pin GPIO_PIN_4
#define CS_GPIO_Port GPIOA
#define LIMIT2_Pin GPIO_PIN_10
#define LIMIT2_GPIO_Port GPIOB
#define LIMIT2_EXTI_IRQn EXTI15_10_IRQn
#define STEP7_Pin GPIO_PIN_14
#define STEP7_GPIO_Port GPIOB
#define STEP4_Pin GPIO_PIN_6
#define STEP4_GPIO_Port GPIOC
#define STEP1_Pin GPIO_PIN_7
#define STEP1_GPIO_Port GPIOC
#define LIMIT5_Pin GPIO_PIN_8
#define LIMIT5_GPIO_Port GPIOC
#define LIMIT5_EXTI_IRQn EXTI9_5_IRQn
#define DIR6_Pin GPIO_PIN_10
#define DIR6_GPIO_Port GPIOA
#define EN_Pin GPIO_PIN_11
#define EN_GPIO_Port GPIOA
#define DIR7_Pin GPIO_PIN_12
#define DIR7_GPIO_Port GPIOA
#define DIR5_Pin GPIO_PIN_10
#define DIR5_GPIO_Port GPIOC
#define DIR4_Pin GPIO_PIN_11
#define DIR4_GPIO_Port GPIOC
#define DIR3_Pin GPIO_PIN_12
#define DIR3_GPIO_Port GPIOC
#define DIR2_Pin GPIO_PIN_2
#define DIR2_GPIO_Port GPIOD
#define LIMIT3_Pin GPIO_PIN_5
#define LIMIT3_GPIO_Port GPIOB
#define LIMIT3_EXTI_IRQn EXTI9_5_IRQn
#define STEP2_Pin GPIO_PIN_6
#define STEP2_GPIO_Port GPIOB
#define LIMIT4_Pin GPIO_PIN_7
#define LIMIT4_GPIO_Port GPIOB
#define LIMIT4_EXTI_IRQn EXTI9_5_IRQn
#define STEP5_Pin GPIO_PIN_8
#define STEP5_GPIO_Port GPIOB
#define STEP6_Pin GPIO_PIN_9
#define STEP6_GPIO_Port GPIOB

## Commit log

2025-12-13 Visualization working and collision checker working but not yet integrated
    - collision_checker package with FCL mesh loading (Assimp)
    - kinematics package with forward kinematics (FK transform computation)
    - GroundTruthGenerator with isSelfCollision(q) method
    - Allowed collision pairs generation (kinematic distance filtering)
    - FK integration eliminates false positive collisions
    - Tested: zero false collisions at valid configurations
2026-01-26 unify project components into AR6 repository
    [Gripper_Body.STL, L1.STL, L2.STL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]
2026-01-26 refactor: rename robot_controller to urdf_standalone
    [Gripper_Body.STL, L1.STL, L2.STL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]
2026-01-26 added readme
    [Gripper_Body.STL, L1.STL, L2.STL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]
2026-01-27 updated doc and rename for controller
    [Gripper_Body.STL, L1.STL, L2.STL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]

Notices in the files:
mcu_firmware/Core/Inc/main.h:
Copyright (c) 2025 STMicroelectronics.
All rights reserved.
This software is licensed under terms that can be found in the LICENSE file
